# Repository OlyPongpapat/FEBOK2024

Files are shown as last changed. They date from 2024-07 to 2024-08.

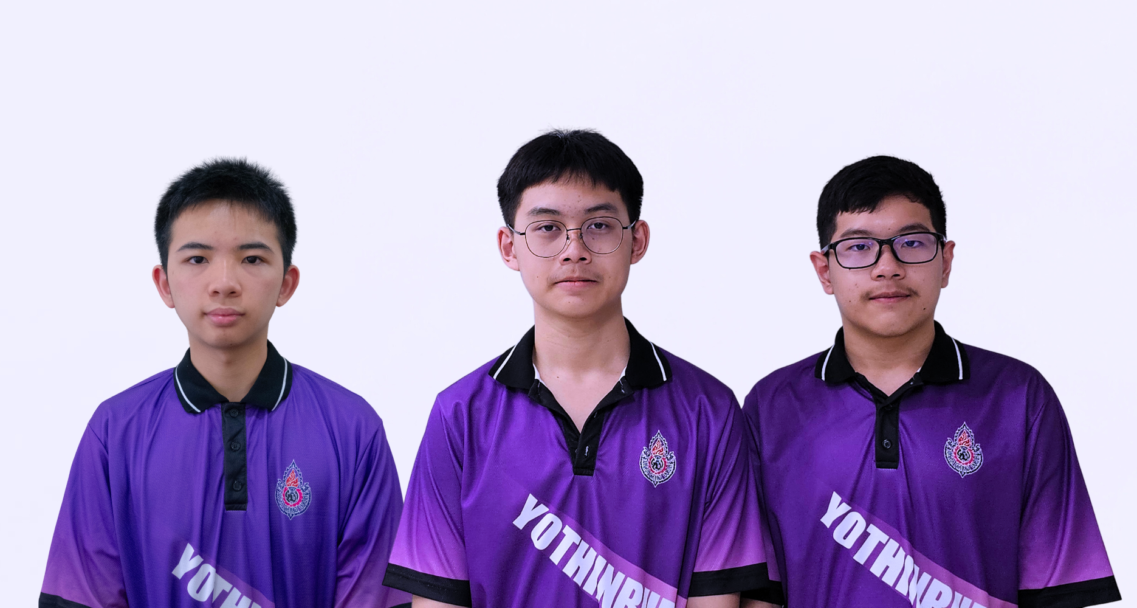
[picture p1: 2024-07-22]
Team Photos/Team Photo (Formal).png

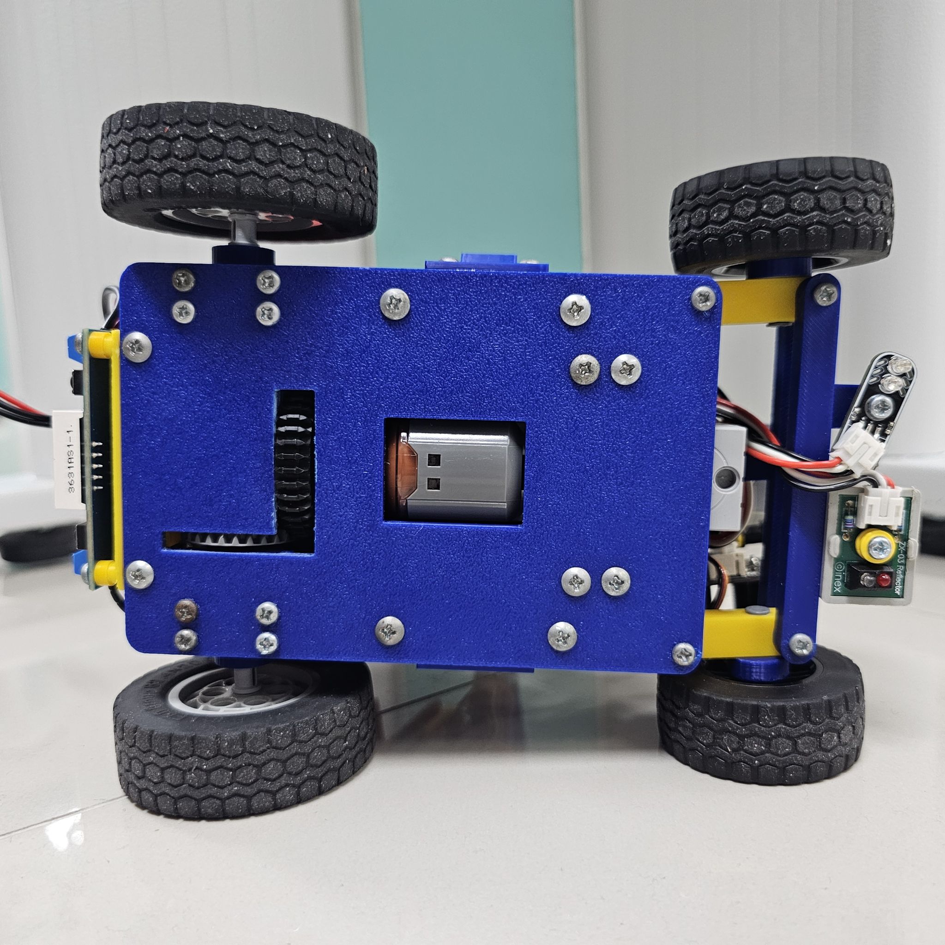
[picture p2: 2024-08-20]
Vehicle Photos/Bottom.jpg

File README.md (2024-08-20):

### ***WE ARE TEAM YBR-BOK***

<p align="center">
  
</p>
<p align="center">
 by Yothinburana School

# **About Us.**

### **This is our team.**

  We are team YBR-BOK. We are a team from Yothinburana School in Bangkok, Thailand. Our team is comprised of 3 members; Pawit Nateenantasawasd, Pongpapat Putongkam, and Thanyawut Krittikanon.
For the past 4 years, we have been good friends, classmates, and teammates. Last year, our first time competing in this WRO category, we got lucky and had a chance to compete in the international round. But we are not careful enough, our rookie mistake gets us only in 8th place. This year we hope to get one more chance before the regulations change to redeem ourselves.

<p align="center">
    
</p>

Programmer: Pawit Nateenantasawasd </p>
Mechanic: Pongpapat Putongkam </p>
Support: Thanyawut Krittikanon </p>

</p>

  Our team has 3 major positions. Firstly, Pawit Nateenantasawasd (the middle person). He is the programmer of our team. He is quite introverted so he can focus for a very long time. On the other hand, Pongpapat Putongkam (the left person). He has a very short attention span, so he could come up with new ideas easily. He is the designer and builder of our robot. Lastly, Thanyawut Krittikanon (the right person). He is at the best of both worlds. He can program and design, so he is a supporter of the team. Our team name is YBR-BOK. 'YBR' stands for 'Yothinburana Robot Club', and 'BOK' comes from our nickname 'Book, O'ly, Kaopun'.

# Content
`3DModels` This folder includes the 3D design of the vehicle and the rendered model of the vehicle.

`Schemes` This folder contains one or more schematic diagrams in JPEG, PNG, or PDF format that depict the electromechanical components of the vehicle. These diagrams illustrate all the elements, including electronic components and motors, and show how they are interconnected.

`Source Codes` This folder includes all programming used to participate in the WRO 2024 Future Engineers Category and all the programming flowcharts.

`Team Photos` This folder includes photos of the team participating in the WRO 2024 Future Engineers Category.

`Vehicle Photos` This folder contains photos of the vehicle from all perspectives, including side and bottom views.

`video` This folder contains YouTube links that show how the robot operates to complete both missions.

# **Part 1: ROBOT DESIGN**

Last year, our design was based entirely on Lego. This year we decided to up our game and 3d print the whole thing with ABS and PLA plastic filament reinforced with metal parts and some Lego. Using 3d printed parts allows more flexibility to be implemented and makes it easy to acquire spare parts for an emergency.
Even with all of that, we will still use Lego parts to connect in a very precise area.

## **Parts of our ROBOT**

<br>

- **Board** - Arduino Mega 2560 REV3

<br>
<br>
| Specification | Description |
|---|---|
| Microcontroller |	ATmega2560 |
| Operating | Voltage	5V |
| Input Voltage (recommended)|	7-12V |
| Input Voltage (limit) |	6-20V |
| Digital I/O Pins |	54 (of which 15 provide PWM output) |
| Analog Input | Pins	16 |
| DC Current per I/O Pin |	20 mA |
| DC Current for 3.3V | Pin	50 mA |
| Flash Memory |	256 KB of which 8 KB used by bootloader |
| SRAM	| 8 KB |
| EEPROM	| 4 KB |
| Clock Speed |	16 MHz |
| LED_BUILTIN |	13 |
| Dimensions | 101.5mm x 53.3mm |

It's a popular microcontroller board based on the ATmega2560 processor, featuring a large number of digital and analog I/O pins, making it suitable for complex projects that require a lot of inputs and outputs like Future Engineer. Having a lot of ports get rid of the problem that we do not have enough ports to connect 'OpenMV camera' while using 'Gyro'. This is why we trust and select Arduino Mega 2560 REV3.

<br>

- **Sensor Shield** - IO Sensor Shield Due (By DF ROBOT)

<br>
<br>
| Specification | Description |
|---|---|
| Xbee slots | 3 slots |
| MicroSD slot | 1 slots |
| Power selector | To select between Arduino Mega power or external power |
| Extended TTL connection pins | for 4 Serial ports |
| support | most of the arduino shield |
| Dimensions | 125 x 57 mm |

This extra-large shield features three Xbee slots, a microSD slot, and Arduino shield headers compatible with most Arduino shields. It also includes a prototyping area and provides breakouts for Digital pins 14 to 53, Analog pins 6 to 15, and PWM pins 2 to 9. With these capabilities, this shield can serve as a key communication hub for your projects.

<br>

- **Motor Driver Shield** - IO Expansion Shield V7.1 (By DF ROBOT)

<br>
<br>
| Specification | Description |
|---|---|
| Ports | 3Pins |
| Digital Pins | 14 Pins |
| Analog Pins | 6 Pins |
| The external 5.5V power supply provides 3.3V | Regulated power supply and is compatible with 3.3V components |

It supports both 3.3V and 5V voltages, includes a switch for wireless communication or programming, and features clear, color-coded headers. Key highlights include 14 digital pins (6 with PWM), 6 analog pins, multiple communication interfaces (Xbee, Bluetooth, Wi-Fi), and extended ports for easy module connections. Designed for flexibility, it also supports external power for longer battery life and is compatible with various wireless modules and I2C interfaces.

<br>

- **Driving Motor** ( Power Functions L-Motor )

  <br>
<br>
| Specification | Description |
|---|---|
| Category | Electric Motor |
| Subcategory | Power Functions |
| Theme | Technic™ |
| Brand | LEGO |
| Color | Light Bluish Gray |
| Released in | 2012 |
| Weight | 45 grams |
| Dimensions (LxWxH)  | 5.6 x 2.5 x 3 cm |

The LEGO Power Functions L-Motor (88003) is favored for its compact size, quiet operation, and energy efficiency, making it ideal for integrating into intricate LEGO builds without noise concerns. Its cost-effectiveness and reliable performance further enhance its appeal, providing a balanced option for powering a variety of LEGO creations effectively. The motor comes with a dedicated port for Lego. So, we modified it to make it able to connect to the board.

<br>

- **Camera** - OpenMV

<br>

| Specification | Description |
|---|---|
| Processor | ARM® 32-bit Cortex®-M7 CPU w/ Double Precision FPU, 480 MHz (1027 DMIPS), Core Mark Score: 2400 (compare w/ Raspberry Pi 2: 2340), and RAM Layout (33MB Total)|
| RAM Layout (33MB Total) | 256KB .DATA/.BSS/Heap/Stack, 32MB Frame Buffer/Stack, 512KB SDRAM Cache, 256KB DMA Buffers, and Flash Layout (34MB Total): |
| Flash Layout (34MB Total) | 128KB Bootloader, 32MB Embedded Flash Drive, 1792KB Firmware, and Supported Image Formats |
| Supported Image Formats | Grayscale, RGB565, JPEG (and BAYER/YUV422), and Maximum Supported Resolutions |
| Maximum Supported Resolutions | Grayscale: 2952x1944 (5MP) and under, RGB565: 2952x1944 (5MP) and under, Grayscale JPEG: 2952x1944 (5MP) and under, and RGB565 JPEG: 2952x1944 (5MP) and under |
| Lens Info | Focal Length: 2.8mm, Aperture: F2.0, Format: 1/3", HFOV = 70.8°, VFOV = 55.6°, Mount: M12*0.5, and IR Cut Filter: 650nm (removable) |

<br>

We decided to use this camera instead of the Pixy2.1 due to its excellent visual performance, which allows it to accurately distinguish objects and colors.Additionally, we use this camera to measure the XYZ axes, calculate the center of objects, and further enhance color differentiation accuracy.

<br>

- **Camera Shield** ( LCD Shield Rev 2 ) 

 <br>

| Specification | Description |
|---|---|
| Screen Type | 1.8" TFT LCD |
| Horizontal Resolution | 128 pixels (28.03mm) 0.18mm pixel pitch |
| Vertical Resolution | 160 pixels (35.04mm) 0.18mm pixel pitch |
| Brand | LEGO |
| Display Colors | 64K 16-bit RGB565 |

<br>

We added this component so that when we test the robot without connecting it to the computer, we can still identify any errors that occur.

<br>

- **Servo** ( GEEKSERVO-360 ) one for **steering** our robot and another for rotating **the ultrasonic sensor**

<br>
<br>
| Specification | Description |
|---|---|
| Temperature Range | -20 ℃ to 60 ℃ |
| Operating Temperature  | -10 ℃ to 50 ℃ |
| Electrical Voltage | 4.8V ~ 6V (Servo) / 3V (Motor) |

We use the Geekservo 2kg 360 Degrees for steering the robot and an Ultrasonic Sensor for rotation. This servo is compatible with LEGO, simplifying and streamlining the robot's construction.

<br>

- **Ultrasonic Sensor** ( SEN0307 ) to measure the distance between the robot and the walls

<br>
<br>
| Specification | Description |
|---|---|
| Supply voltage | 3.3 V to 5.5 V |
| Power consumption | 20 mA |
| Measurement range | from 2 cm to 500 cm |
| Resolution | 1 cm |
| Accuracy | 1% |
| Frequency | max. 30 Hz |
| Operating temperature  | -10°C to 70°C |
| Dimensions | 47 x 22 mm |
| Distance calculation | Distance = Vout (mV) x 520 / Vin (mV) |

An impressive sensor with **built-in temperature compensation**, which minimizes measurement errors due to extreme temperatures. It utilizes **analog voltage output** and offers precise distance measurements ranging from **2 to 500 cm** with a 1 cm resolution and **±1% accuracy**.

<br>

- **Color Sensor** - We use the Virus-III designed by Sopon and the ZX-03 designed by INEX to detect the field's colors. The red ZX-03 Reflector is used to detect the blue line, while the green Virus-III is used to detect the red line, allowing us to accurately measure color values on the field.



<br>

- **Gyro** - We use **GY-25** gyro to control the direction of our robot.

<br>

| Specification | Description |
|---|---|
| Chip | MPU-6050 |
| Electrical Voltage | 3 - 5V |
| Communication Modes | Serial Communication (9600, 115200 Baud), I2C Communication  |
| Dimensions | 15.5mm x 11.5mm |
| Pin Spacing | 2.54mm |
| Direct Data Output | Raw Data |
| Pitch Angle (Yaw) | ± 180° |
| Roll Angle (Roll) | ± 180° |
| Yaw Angle (Pitch) | ± 180° |
| Angular Resolution | 0.01° |

Dataset: http://mkpochtoi.ru/GY25_MANUAL_EN.pdf<br>
Library: https://github.com/ElectronicCats/mpu6050

<br>

- **Step Down** - We use a **Step Down** converter to display the battery voltage and regulate the power to the desired level.
<br>
<br>

| Specification | Description |
|---|---|
| Input Voltage | 4-38 VDC |
| Output Voltage | 1.25-36 VDC |
| Output Current Maximum | 5A |
| Chipset | XL4015E1 |
| Dimension | 39mm x 66mm x 18mm (WxLxH) |

<br>

- **ZX-Switch01** - We use the **ZX-Switch01** to facilitate the program's initiation.

<br>

Additional Details:<br>
When the switch is pressed, the DATA pin will be at a logic "1" due to R2, which is connected as a pull-up resistor. Pressing the switch will pull the DATA pin to "0" by creating a short circuit to ground. This causes current to flow through the LED and R1, making the LED light up brightly. Additionally, the DATA pin can also function as an input, allowing you to control the LED's on and off state as needed.

<br>

- **Power Switch** - We use this switch designed by us to turn the power supplied to the robor on and off.

<br>

# **Part 2 : Programming**
 
##📢 Setting up your Board and Arduino Software 
<br>
❗ Please Note that** ❗> We are using the **Arduino Mega 2560 REV3**. If you choose to replicate our project with a different board, you may need to make some adjustments to the code provided in this repository.

<be>

  # Robot Control System

This project is a basic setup for controlling a robot with two motors, two servos, and various sensors using an Arduino-compatible platform. The code leverages a PID controller for precise motor control, along with a servo to manage steering and an ultrasonic sensor for obstacle detection.

## Components

- **Motors**: The robot is equipped with two motors. Each motor's speed and direction are controlled using specific pins defined in the code.
- **Servos**: Two servos (`myservo1` and `myservo2`) are used, one for steering and another for positioning an ultrasonic sensor.
- **PID Controller**: A PID controller is implemented to manage motor speeds for better control over the robot's movements.
- **Sensors**: 
  - **IMU/Compass**: Used for tracking the robot's yaw, roll, and pitch.
  - **Ultrasonic Sensor**: Used for distance measurement to detect obstacles.
  - **Light Sensors**: Red and green light sensors are used for detecting environmental conditions.
  - **Button**: A button is used for user input to start or stop the robot.

## Code Overview

```cpp
#include "Mapf.h"
#include "Servo.h"
#include <PID_v2.h>

Servo myservo1;
Servo myservo2;

float pvYaw, pvRoll, pvPitch;
uint8_t rxCnt = 0, rxBuf[8];

const int E1Pin = 10;
const int M1Pin = 12;

typedef struct {
  byte enPin;
  byte directionPin;
} MotorContrl;

const int M1 = 0;
const int MotorNum = 1;

const MotorContrl MotorPin[] = { {E1Pin, M1Pin}, {E2Pin, M2Pin} };

int const STEER_SRV = 23;
int const ULTRA_SRV = 16;

int const ULTRA_PIN = A9;
int const RED_SEN = A6;
int const GEEN_SEN = A7;
int const BUTTON = A8;

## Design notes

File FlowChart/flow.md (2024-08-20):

  OPEN ROUND - 

  Open drawio

  OBSTACLE ROUND - 

  แบบแผนที่ยังไม่ได้ตั้งชื่อ drawio

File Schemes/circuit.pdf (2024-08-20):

# Step Down

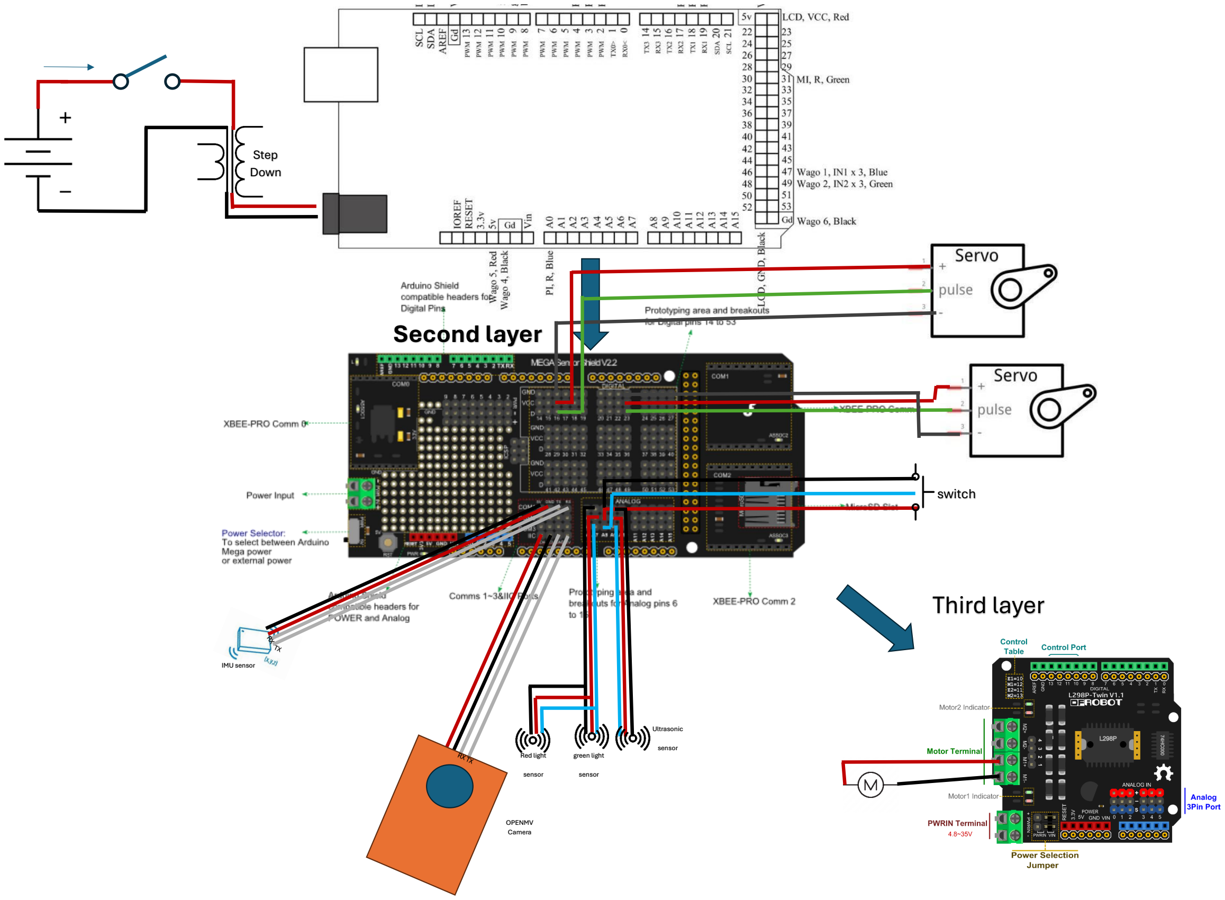
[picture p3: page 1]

# Second layer

Red light

sensor

green light

sensor

Ultrasonic

sensor

# switch

OPENMV
Camera

# Third layer

IMU sensor

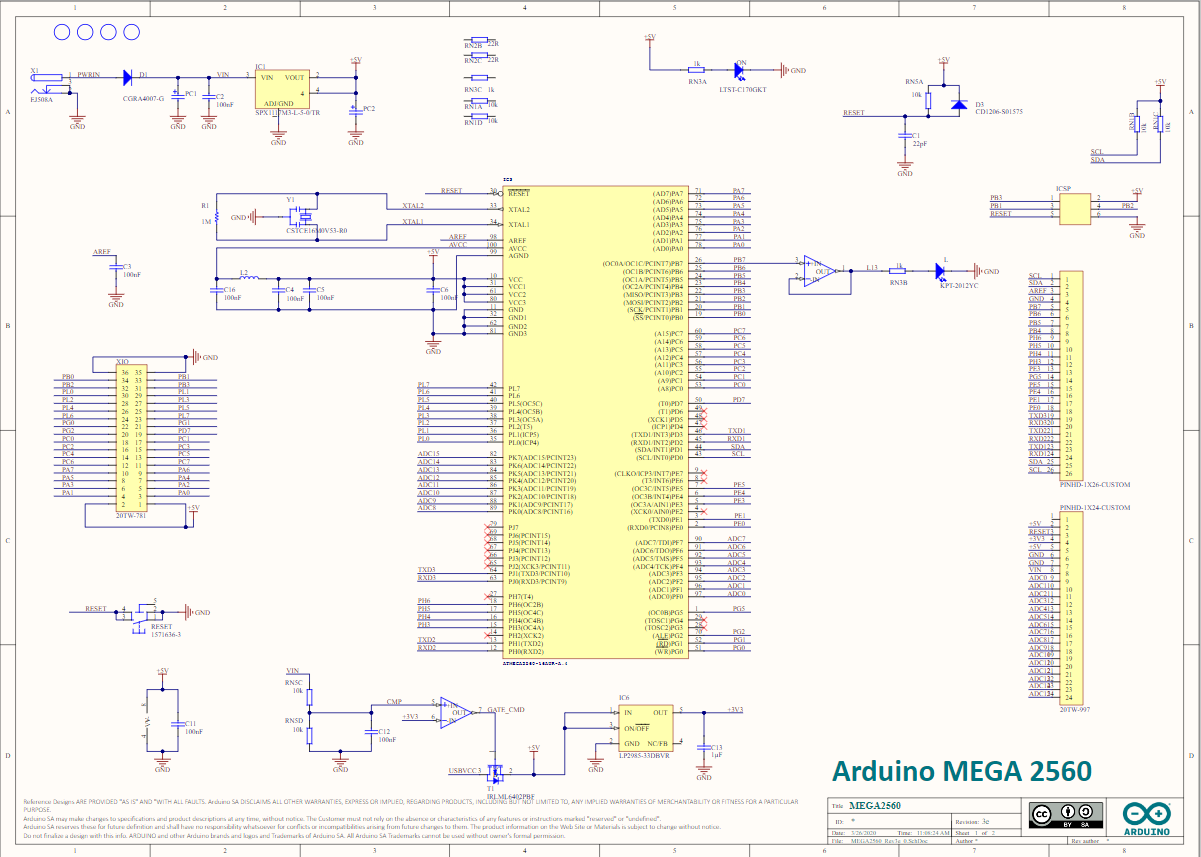
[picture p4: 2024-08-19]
Schemes/Arduino Mega 2560 Rev3 .png

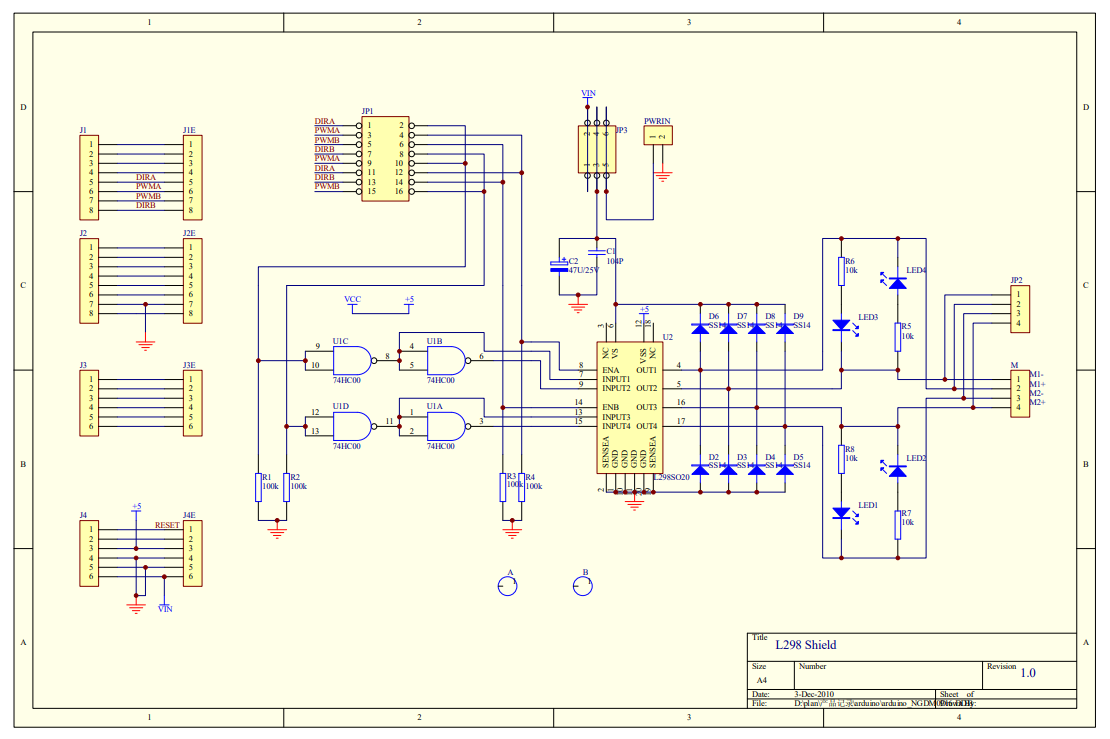
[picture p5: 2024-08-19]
Schemes/2x2A DC Motor Shield for Arduino.png

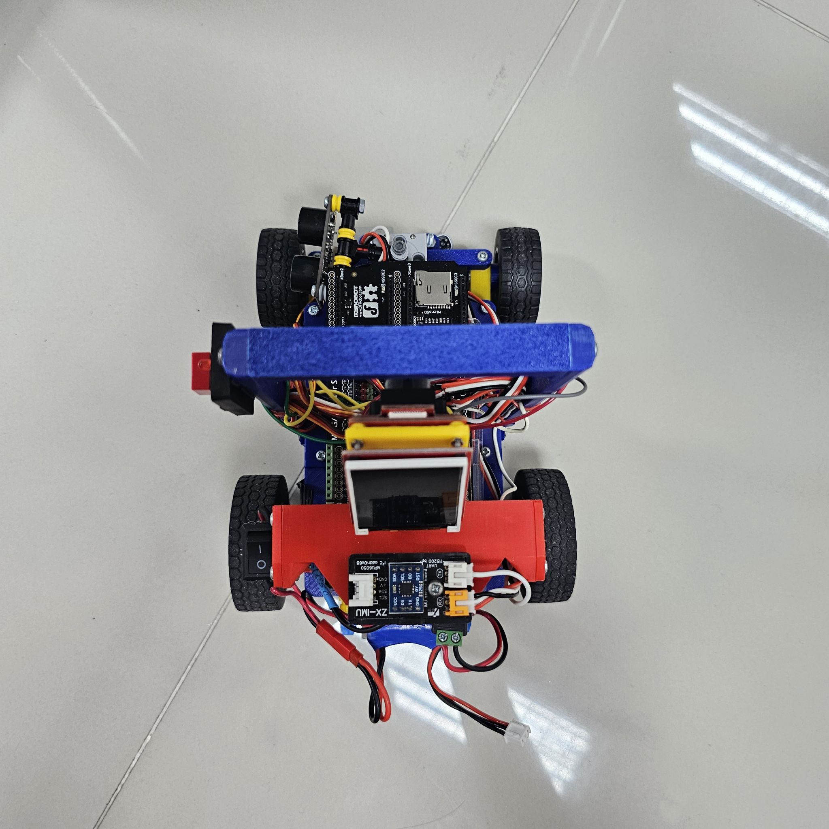
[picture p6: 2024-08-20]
Vehicle Photos/Top.jpg

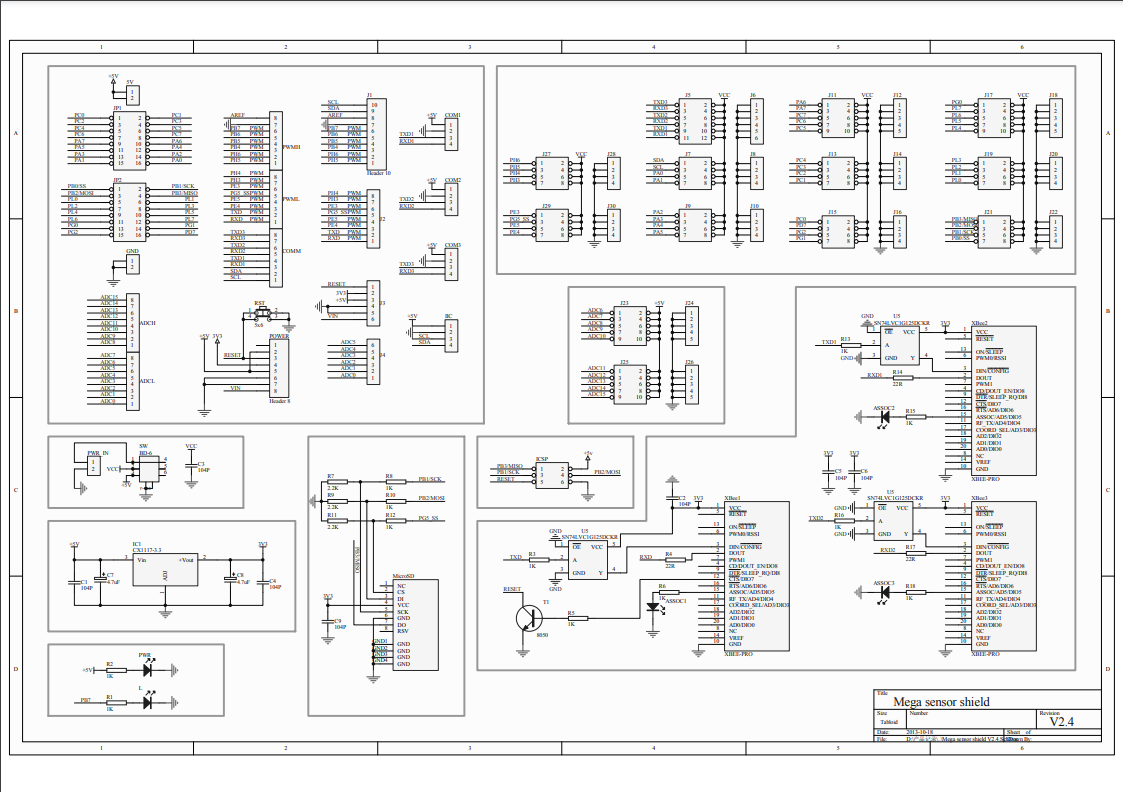
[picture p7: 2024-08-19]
Schemes/Gravity: IO Sensor Shield For Arduino Mega Due.png

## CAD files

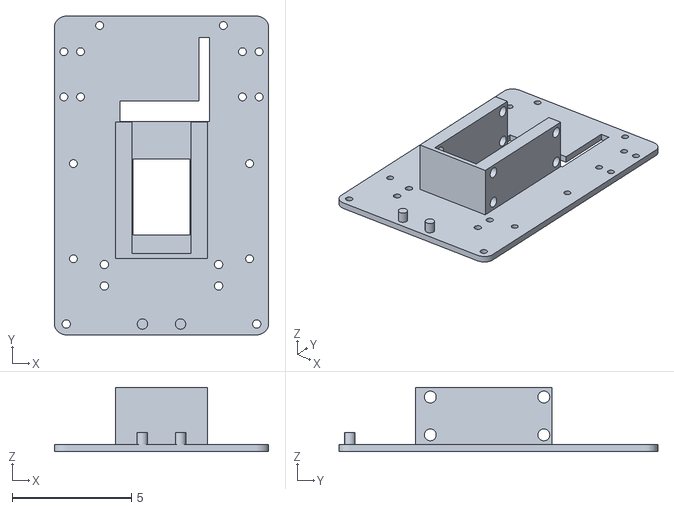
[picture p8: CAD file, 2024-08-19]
3d-model/MAIN PLATE.stl
9.00 x 13.4 x 2.70

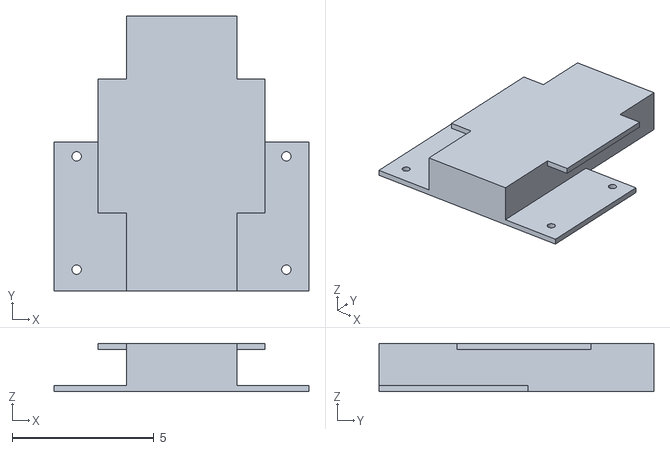
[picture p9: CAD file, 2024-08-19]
3d-model/batt box.stl
9.00 x 9.70 x 1.71

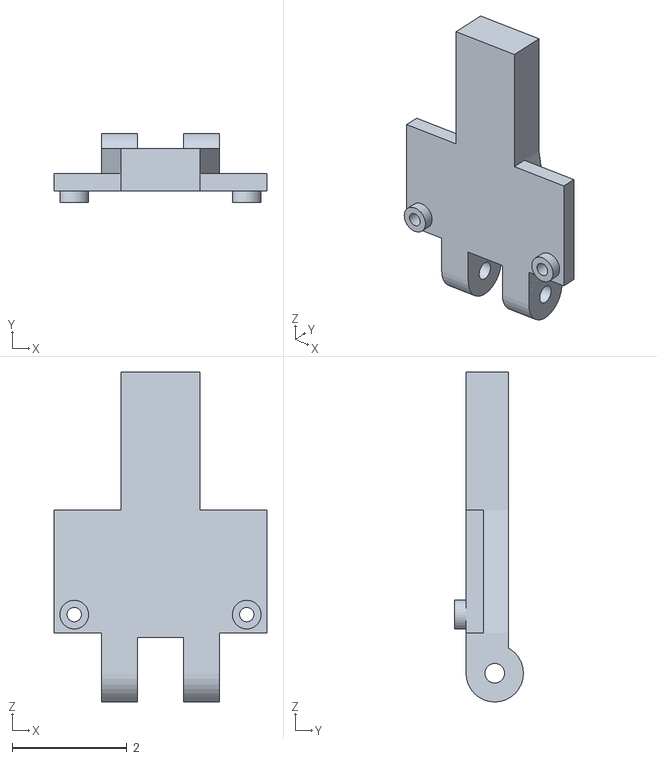
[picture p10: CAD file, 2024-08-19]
3d-model/CAM PLATE V3.stl
3.70 x 1.20 x 5.74

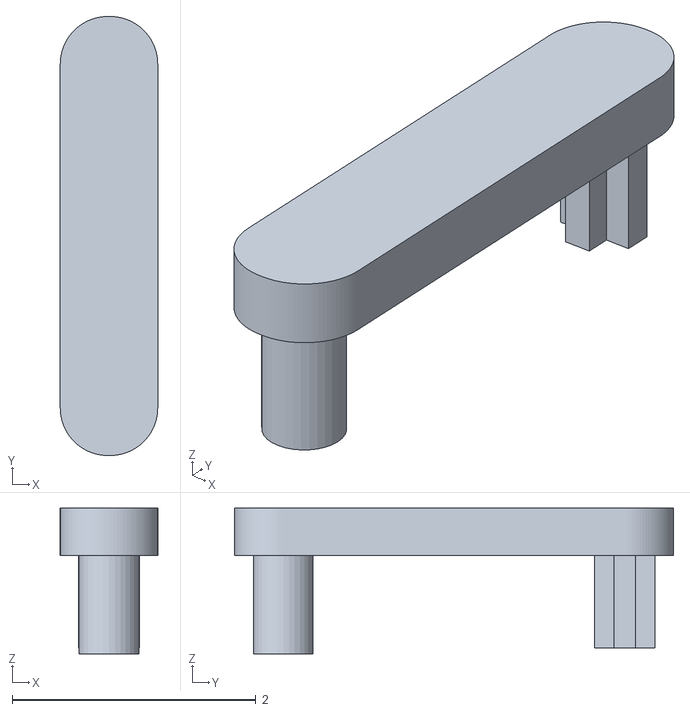
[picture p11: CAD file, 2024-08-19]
3d-model/Turn Leg.stl
0.8 x 3.60 x 1.19

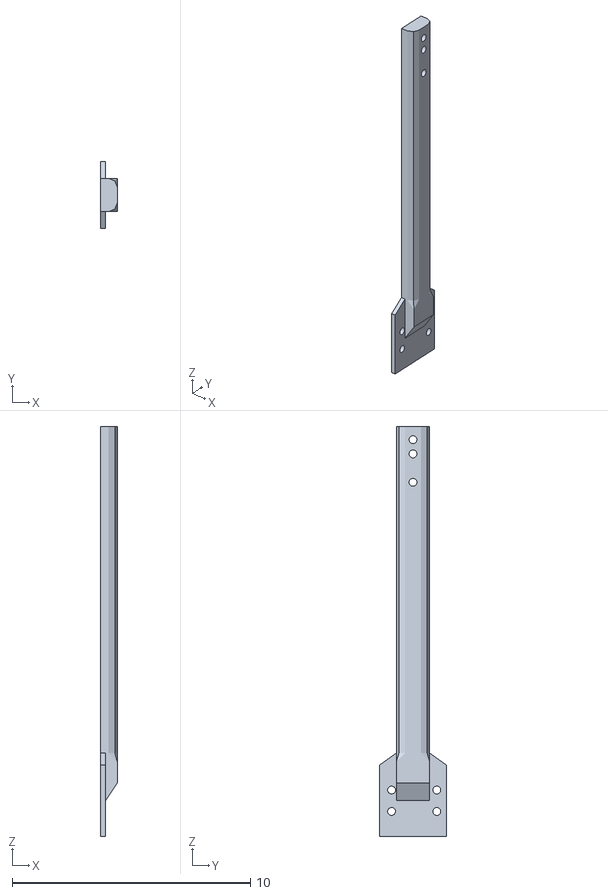
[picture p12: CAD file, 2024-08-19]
3d-model/hand pole 1.stl
0.7 x 2.80 x 17.2

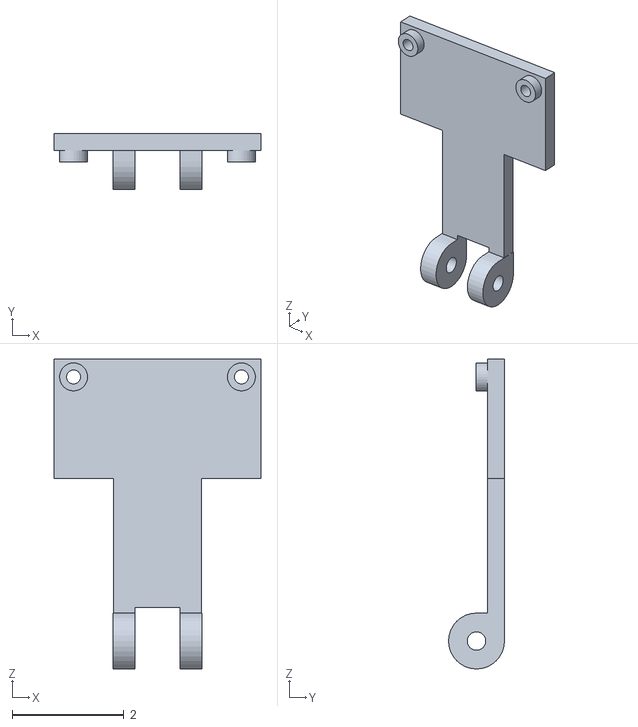
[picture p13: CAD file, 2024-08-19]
3d-model/cam plate 2.stl
3.70 x 1.00 x 5.54

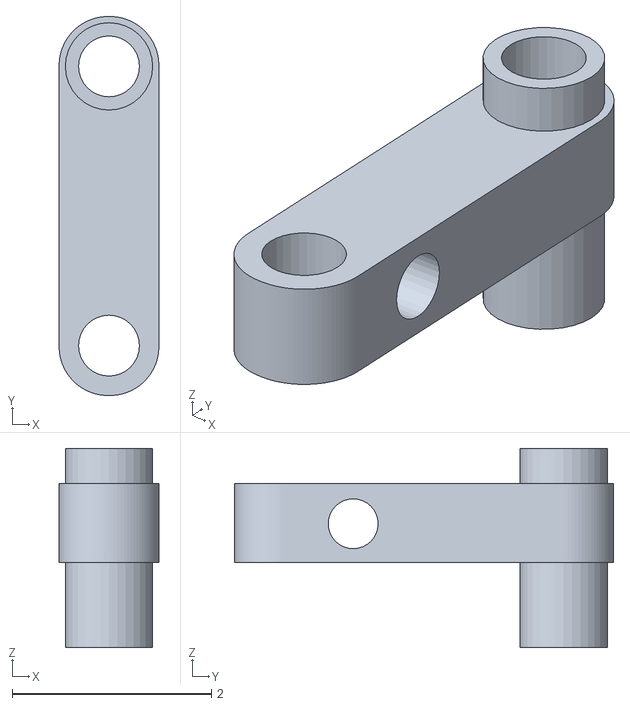
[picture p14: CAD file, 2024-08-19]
3d-model/leg L.stl
1.00 x 3.80 x 2.00

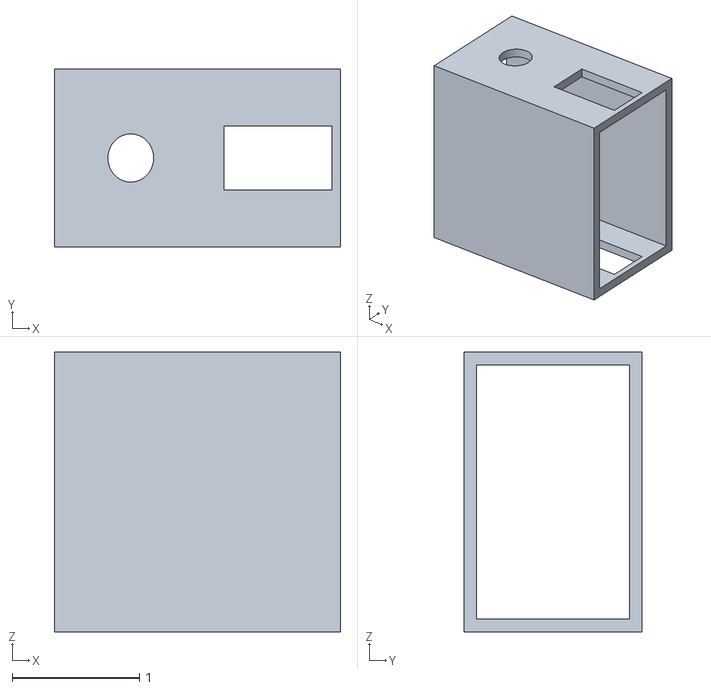
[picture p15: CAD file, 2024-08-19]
3d-model/switch box.stl
2.25 x 1.40 x 2.20

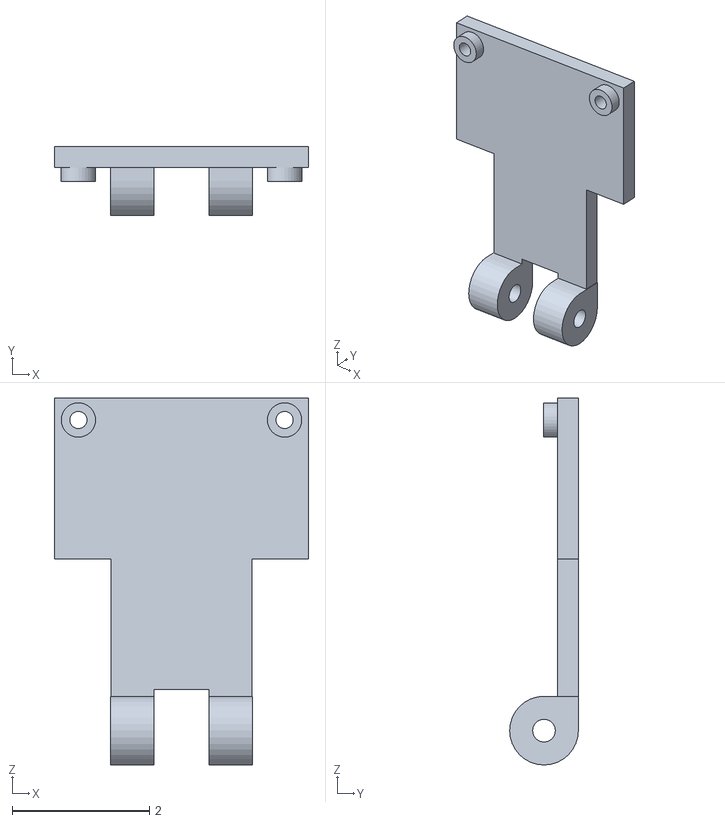
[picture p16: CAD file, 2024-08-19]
3d-model/cam plate.stl
3.70 x 1.00 x 5.34

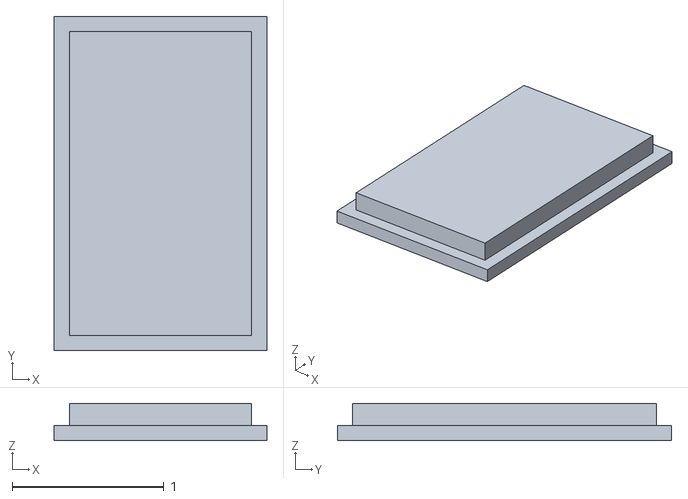
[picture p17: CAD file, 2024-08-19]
3d-model/switch cov.stl
1.40 x 2.20 x 0.245

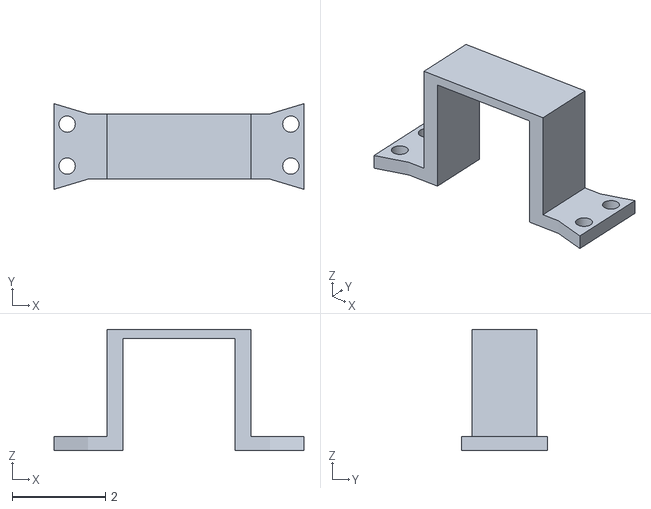
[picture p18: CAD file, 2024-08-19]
3d-model/servo Bracket.stl
5.36 x 1.84 x 2.60

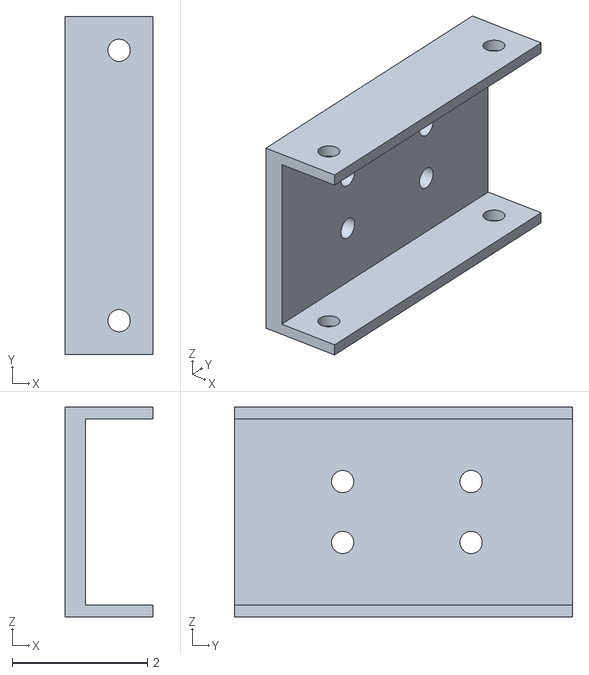
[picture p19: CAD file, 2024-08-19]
3d-model/pole 2.stl
1.30 x 5.00 x 3.10

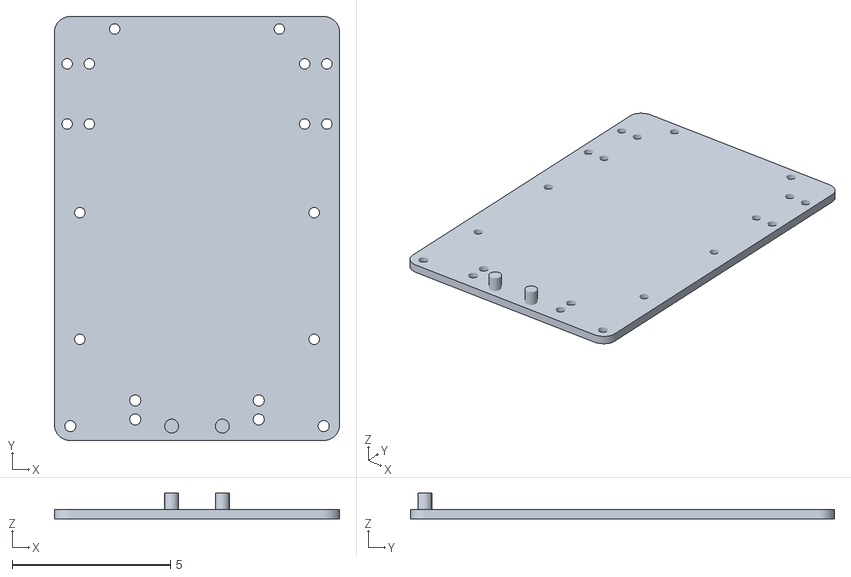
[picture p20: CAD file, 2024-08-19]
3d-model/top plate.stl
9.00 x 13.4 x 0.815

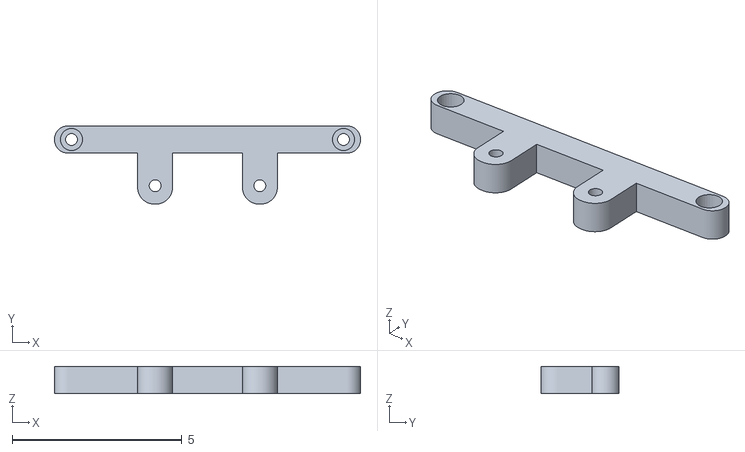
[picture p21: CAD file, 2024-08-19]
3d-model/bar 2.stl
9.00 x 2.30 x 0.8

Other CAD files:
3d-model/step down.stl
3d-model/cam top.stl
3d-model/servo Bracket 2.stl
3d-model/bar 2 v2.stl
3d-model/axel sup L.stl
3d-model/axel sup R.stl
3d-model/bar 1.stl
3d-model/bar 3 v2.stl
3d-model/bar 3.stl
3d-model/burger.stl
3d-model/cam plate 3.stl
3d-model/cam pole 1.stl
3d-model/cam pole 2.stl
3d-model/hand pole 2.stl
3d-model/hand pole top.stl
3d-model/leg R.stl
3d-model/open plate.stl
3d-model/pole 1.stl

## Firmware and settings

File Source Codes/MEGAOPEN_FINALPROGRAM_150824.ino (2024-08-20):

//red red425 white519 blue94
//blue red316 white950 blue350\
//700 500
//335
//700
#include "Mapf.h"
#include "Servo.h"
#include <PID_v2.h>

Servo myservo1;
Servo myservo2;

//  Compass Variables
float pvYaw, pvRoll, pvPitch;
uint8_t rxCnt = 0, rxBuf[8];

//  Motor B
const int E1Pin = 10;
const int M1Pin = 12;
const int E2Pin = 11;
const int M2Pin = 13;

/**inner definition**/
typedef struct {
  byte enPin;
  byte directionPin;
} MotorContrl;

const int M1 = 0;
const int MotorNum = 1  ;

const MotorContrl MotorPin[] = { {E1Pin, M1Pin}, {E2Pin, M2Pin} } ;

const int Forward = LOW;
const int Backward = HIGH;

//  Servos
int const STEER_SRV = 23;
int const ULTRA_SRV = 16;

//  Ultrasonic Sensor
int const ULTRA_PIN = A9;

//  Light Sensors
int const RED_SEN = A6;
int const GEEN_SEN = A7;

//  Button
int const BUTTON = A8;

char TURN = 'U';
int compass_offset = 0;
long halt_detect_line_timer;
bool found_block = false;
int Servo_Value;
int x = 1;
int Y = 20;
int count = 0;

// Specify the links and initial tuning parameters
PID_v2 compassPID(0.6, 0.0001, 0.02, PID::Direct);

void setup() {
  compassPID.Start(0, 0, 0);
  compassPID.SetOutputLimits(-180, 180);
  compassPID.SetSampleTime(10);
  pinMode(E1Pin, OUTPUT);
  pinMode(M1Pin, OUTPUT);
  pinMode(STEER_SRV, OUTPUT);
  pinMode(ULTRA_SRV, OUTPUT);
  pinMode(ULTRA_PIN, INPUT);
  pinMode(RED_SEN, INPUT);
  pinMode(GEEN_SEN, INPUT);
  pinMode(BUTTON, INPUT);
  Serial.begin(9600);
  initMotor();
  myservo1.attach(STEER_SRV, 600, 2400);
  myservo2.attach(ULTRA_SRV, 600, 2400);
  steering_servo(0);
  ultra_servo(0, 'L');
  // check_leds();
  while (analogRead(BUTTON) > 500)
    ;
  zeroYaw();
  while (analogRead(BUTTON) <= 500)
    ;
}

void loop() {
  // getIMU();
  // Serial.println(pvYaw);
  // //(❁´◡`❁);
  while (analogRead(BUTTON) > 500) {
    getIMU();
    line_detection();
    int wall_distance = getDistance();
    motor_and_steer((1 * x) * compassPID.Run((x * pvYaw) + ((wall_distance - Y)) * ((float(TURN == 'TURN') - 0.5) * 2)) * -1);
    ultra_servo(pvYaw,TURN);
    if (count >= 12) {
      long timer01 = millis();
      while (millis() - timer01 < 1700) {
        getIMU();
        line_detection();
        motor_and_steer((1 * x) * compassPID.Run((x * pvYaw) + ((wall_distance - Y)) * ((float(TURN == 'TURN') - 0.5) * 2)) * -1);
        ultra_servo(pvYaw,TURN);
      }
      setMotorSpeed( M1 , 0 );
      while (true) {
      }
    }
  }
    setMotorSpeed( M1 , 0 );
  while (analogRead(BUTTON) <= 500)
    ;
  while (analogRead(BUTTON) > 500)
    ;
  while (analogRead(BUTTON) <= 500)
    ;
}

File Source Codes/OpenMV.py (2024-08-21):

import sensor, image, time, math
from pyb import UART

# Initialize the sensor
sensor.reset()
sensor.set_pixformat(sensor.RGB565)
sensor.set_framesize(sensor.QQVGA)
sensor.skip_frames(time=2000)
clock = time.clock()

# Initialize UART (change 3 to 1 if using UART1)
uart = UART(3, 19200)

# Color thresholds
red_threshold = (30, 100, 15, 127, 15, 127)
green_threshold = (0, 58, -128, -25, -128, 127)

focalLength = 2.3
targetHeight = 10
cameraFOV = 80.0
frameWidth = 160
frameHeight = 120

avoidance_degree = 0
Blocks_TURN = None

def calculate_avoidance():
    global avoidance_degree, Blocks_TURN
    found_block = False

    img = sensor.snapshot()

    red_blobs = img.find_blobs([red_threshold], pixels_threshold=100, area_threshold=100, merge=True)
    green_blobs = img.find_blobs([green_threshold], pixels_threshold=100, area_threshold=100, merge=True)

    largest_blob = None
    largest_blob_area = 0
    signature = None

    all_blobs = [(1, blob) for blob in red_blobs] + [(2, blob) for blob in green_blobs]

    for sig, blob in all_blobs:
        if blob.h() > 1.33 * blob.w():
            object_area = blob.w() * blob.h()
            found_block = True
            if object_area > largest_blob_area:
                largest_blob = blob
                largest_blob_area = object_area
                signature = sig

    if signature is not None and largest_blob:
        object_height = largest_blob.h()
        distance = (targetHeight * focalLength * 100) / object_height

        block_center_x = largest_blob.cx()
        block_center_y = largest_blob.cy()

        delta_x = block_center_x - frameWidth / 2
        detected_degree = delta_x * (cameraFOV / frameWidth)

        block_position_x = distance * math.sin(math.radians(detected_degree))
        block_position_y = distance * math.cos(math.radians(detected_degree)) - 17

        if signature == 1:  # Red object
            avoidance_degree = max(math.degrees(math.atan2(block_position_x + 9, block_position_y)), 5)
            Blocks_TURN = 'R'
        else:  # Green object
            avoidance_degree = min(math.degrees(math.atan2(block_position_x - 9, block_position_y)), -5)
            Blocks_TURN = 'L'

        uart.write("%f\n" % avoidance_degree)  # Send avoidance degree to Arduino

    return avoidance_degree

while True:
    avoidance_degree = calculate_avoidance()
    print("Avoidance Degree: ", avoidance_degree)
    print("Turn Direction: ", Blocks_TURN)

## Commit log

2024-08-19 Rename Screenshot 2024-08-19 223119.png to Arduino Mega 2560 Rev3 .png
2024-08-19 Rename Screenshot 2024-08-19 223433.png to Gravity: IO Sensor Shield For Arduino Mega Due
2024-08-19 Rename Gravity: IO Sensor Shield For Arduino Mega Due to Gravity: IO Sensor Shield For Arduino Mega Due.png
2024-08-19 Rename Screenshot 2024-08-19 223949.png to 2x2A DC Motor Shield for Arduino.png
